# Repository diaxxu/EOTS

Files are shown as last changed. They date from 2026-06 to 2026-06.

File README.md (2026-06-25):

# Project EOTS: Dual-Axis FOC Gimbal
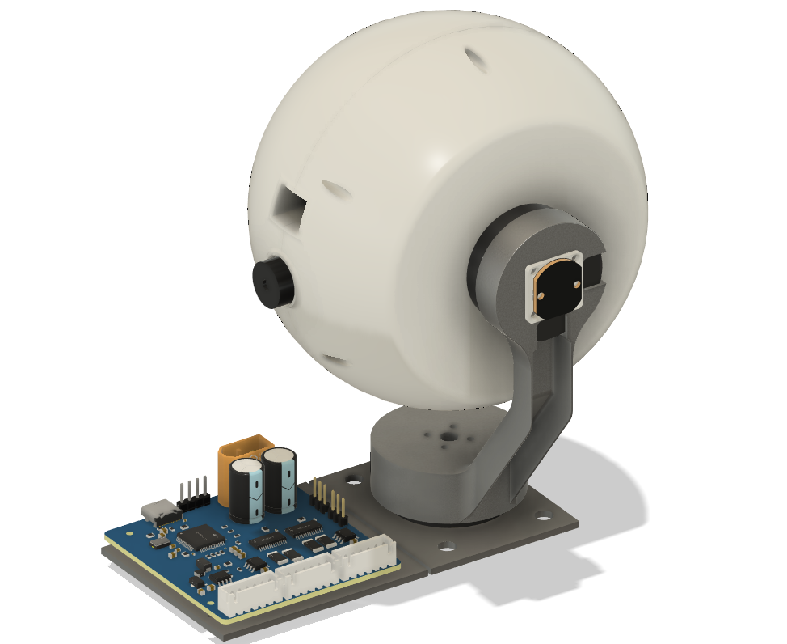
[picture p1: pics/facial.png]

A highly responsive and smooth gimbal capable of tracking targets up to 50m and with the help of two powerful brushless motors its made to be as cheap as possible with almost no drawback it can see thermal vision and normal vision

# Why did i make it

I wanted to build camera system that can track anything say drones, planes and cars. Introducing a high-precision, from-scratch Electro-Optical Targeting System (EOTS). Built with Field Oriented Control (FOC) for continuous, high-torque stabilization, it features a dual-camera sensor payload for synchronized thermal tracking and optical zoom.

- [Project EOTS: Dual-Axis FOC Gimbal](#project-eots-dual-axis-foc-gimbal)
- [Core System Architecture](#core-system-architecture)
  - [Embedded Control & Power Distribution](#embedded-control--power-distribution)
  - [Mechatronics & Actuation](#mechatronics--actuation)
  - [Optical Payload](#optical-payload)
- [(BOM)](#hardware-manifesto-bom)

---

##  Repository Structure

```text
Project-EOTS/
├── README.md                      
├── BOM.csv                        
├── zine.pdf                       
│
├── PCB/                     
│   ├── gerbers.zip                
│   ├── eots_schematic.json     
│   └── BOM.csv
│   └── PickAndPlace.csv
│
├── CAD/                    
│   ├── Assembly      
│   ├── 3d printables
│   ├── 3D metal printing│
│   ├── EOTS.step
│
└── Firmware/                      
    ├── FOC_Gimbal_Driver_STM32/   
    │   ├── main.cpp              
    │   └── platformio.ini         
    │
    ├── RPi_Zero2W_Camera_Server/  
    │   ├── stream_server.py      
    │   └── requirements.txt       
    │
    └── Ground_Control_Station/    
        ├── main.py                
        ├── tracking.py            
        └── hud_display.py
```

# Core System Architecture

The custom 4-layer control board isolates high-frequency digital lines from high-current motor return paths to preserve analog signal integrity. 

## Embedded Control & Power Distribution
* **Microcontroller:** STM32F405RGT6 running custom embedded FOC loops.
* **Gate Drivers:** Dual DRV8313 triple half-bridge drivers managing motor phase currents.
* **Interconnects:** 6-pin JST-XH vertical locking headers (B6B-XH-A) route encoder inputs directly into the MCU timers.
* **Power Delivery:** Main system power is distributed via a high-amperage XT60 connector.
### Schematics 
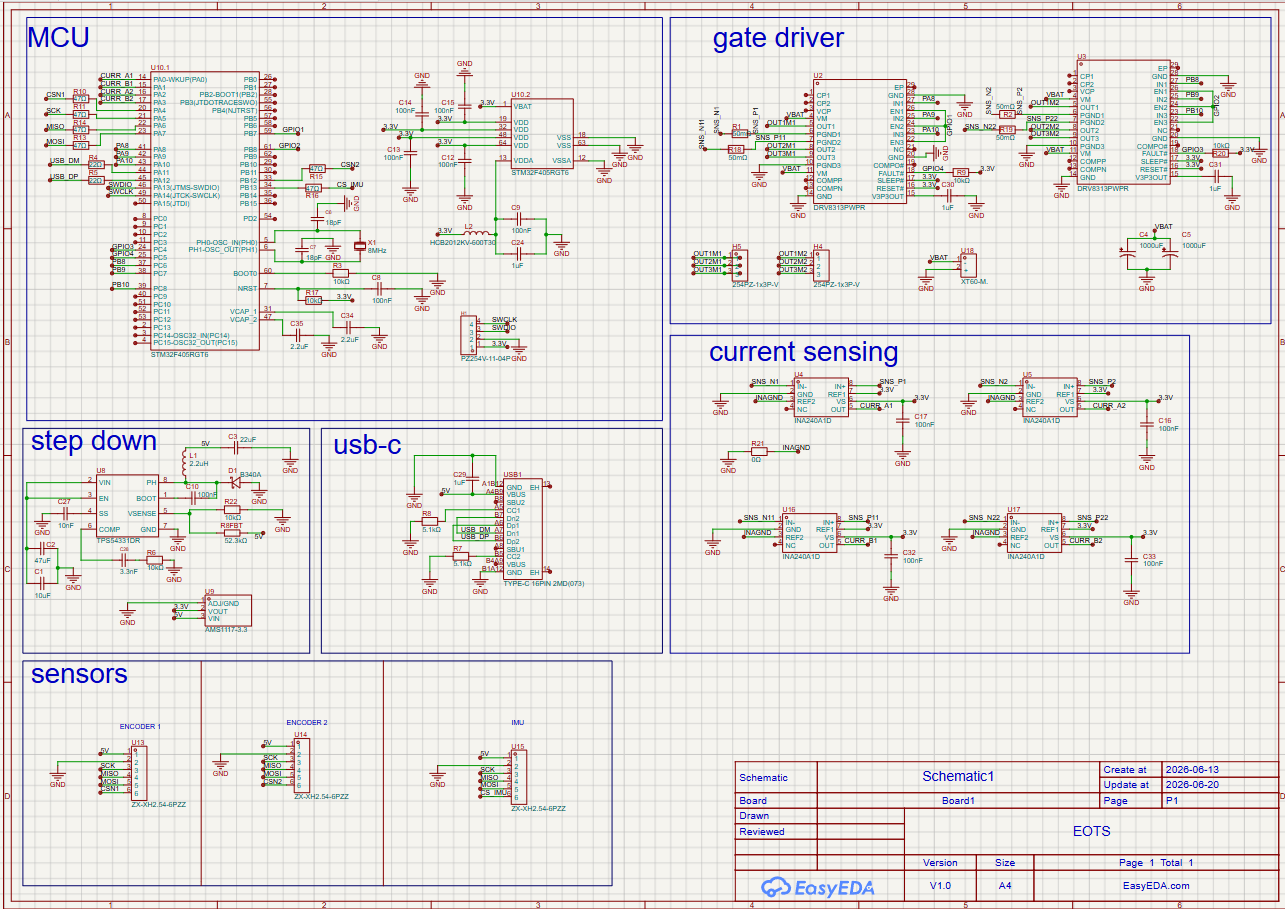
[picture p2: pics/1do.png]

### Layout
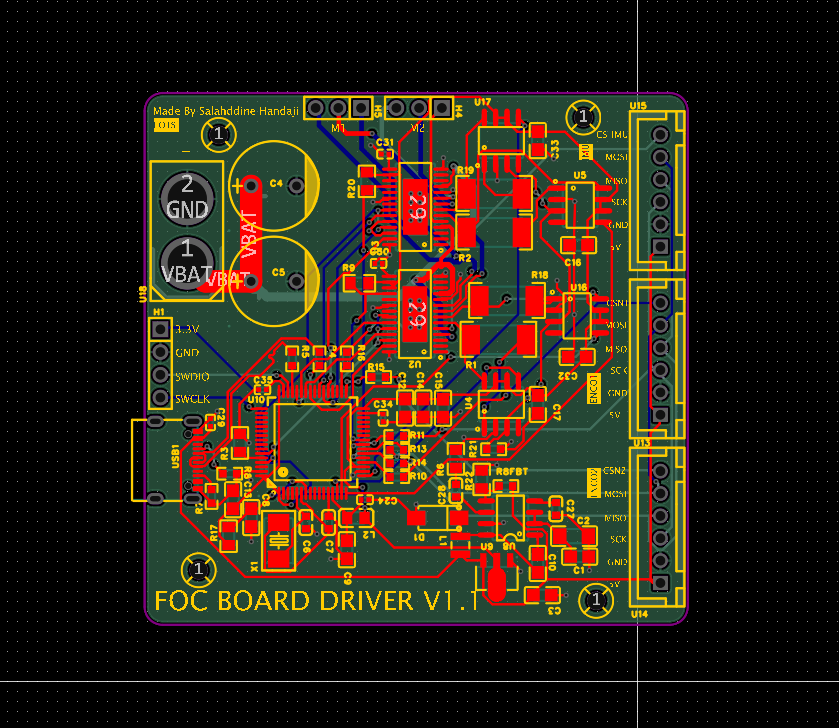
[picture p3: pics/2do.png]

### 3D render
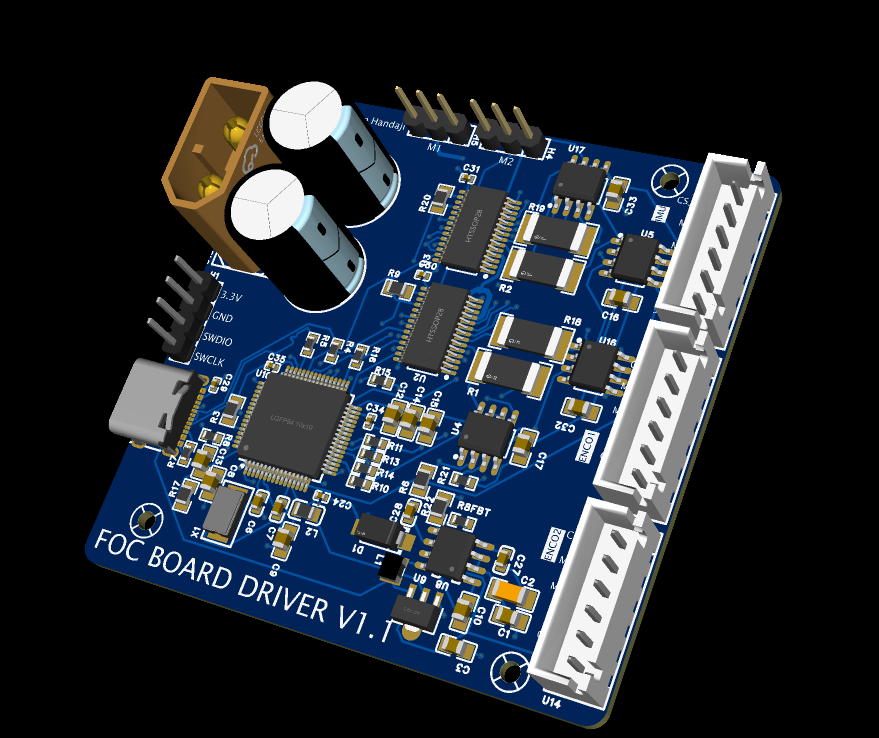
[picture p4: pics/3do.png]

## Mechatronics & Actuation
The mechanical assembly routes power and signals through continuous rotational axes without tangling internal wiring.
* **Actuators:** Dual 2804 100KV brushless motors hard-mounted directly to the structural yoke arms.
* **Sensor Fusion:** An MPU9250 IMU tracks high-speed orientation dynamics in real-time.
* **Feedback Loop:** AS5048A magnetic rotary encoders paired with shaft-mounted diametric neodymium magnets handle absolute angular tracking down to 14-bit resolution.
* **Slip Ring Integration:** A 12-channel MSC-22-12 high-speed capsule slip ring passes continuous USB-C video data through the rotating non-motor pivot arm.
* **Metal chassis:** Metal 3D Printed arm to provide more than enough stability and rigidity.  

## Optical Payload
The sealed sphere housing protects a dual-sensor array running image processing loops back to a central hub.
* **Primary Optical:** IMX219 high-resolution camera module for target detection and optical zoom tracking.
* **Thermal Matrix:** AMG8833 8x8 infrared thermopile array for long-wave thermal signature targeting.
* **Processing Unit:** Raspberry Pi Zero 2 W handles localized video streaming, telemetry generation, and targeting overlays.
  
---

##  How to Use It

Follow these steps to set up, flash, assemble, and operate the EOTS gimbal:

### 1. Hardware Assembly & Mechanical Setup
* **Mount the Actuators:** Secure the two 2804 100KV brushless motors into their respective pan and tilt axis slots on the custom metal 3D-printed yoke chassis.
* **Route the Wiring:** Feed the motor and camera wiring through the center of the 12-wire slip ring to ensure the panning axis can rotate infinitely without binding or straining the cables.
* **Secure the Payload:** Mount the dual-camera housing (containing the IMX219 optical camera and AMG8833 thermal array) onto the tilt axis bracket, ensuring the AS5048A magnetic encoders align perfectly with the motor magnets for precise feedback.

### 2. Flashing the FOC Board Firmware
* **Connect to Power/Data:** Plug a USB-C data cable into the onboard port of the custom FOC driver board.
* **Compile & Flash:** Open the source code located in the `/Firmware` directory using your preferred IDE (e.g., VS Code with PlatformIO or Arduino IDE). Select the correct target MCU board and upload the firmware.
* **Calibrate Encoders:** Run the initial calibration routine embedded in the firmware to map the absolute zero-position of the AS5048A magnetic sensors relative to the brushless motor poles.

### 3. System Interconnect & Operation
* **Power Delivery:** Provide main system power via the dedicated power terminals on the custom PCB (ensure voltage matches your motor/driver design limits).
* **Establish Data Links:** Hook up the Raspberry Pi Zero 2 W to the camera payload feeds and connect its communication lines (UART/SPI) to the FOC driver board to transmit tracking adjustments.
* **Initiate Tracking:** Run your external tracking pipeline (such as an OpenCV script processing the video feed) to send real-time target coordinate errors to the gimbal, allowing the closed-loop FOC system to stabilize and lock onto the target.

### Wire Diagram 
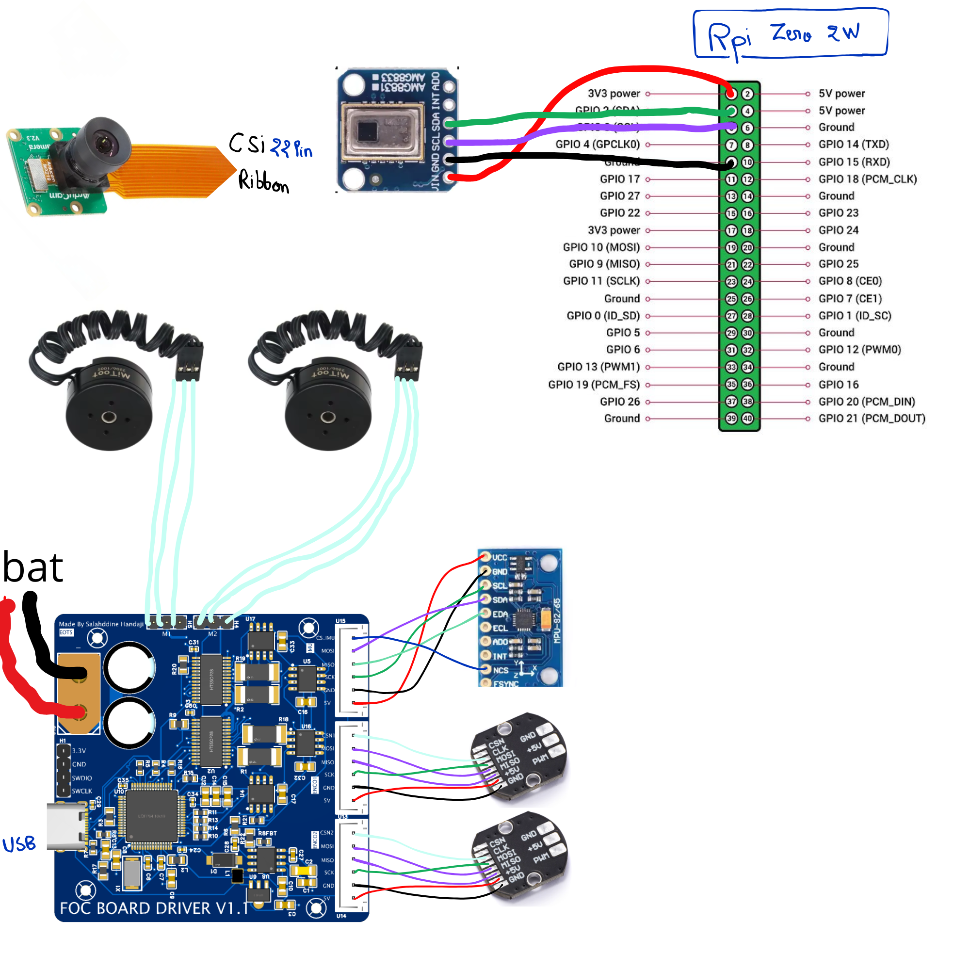
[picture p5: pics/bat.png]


---

# Bill of Materials (BOM)

| Components | Quantity | Price (dh) | Description |
|:---|:---:|:---|:---|
| 2804 100KV Brushless Mo | 2 | 345.42 | Actuators |
| FOC custom pcb | 1 | 1130.99 | Pcb 5 pcba 2 |
| AS5048A | 2 | 194 | Magnetic Encoders magnet included |
| MPU9250 | 1 | OWNED(10) | IMU |
| IMX 219 | 1 | 154.29 | Camera |
| AMG8833 | 1 | 218 | Thermal camera |
| Raspberry Pi Zero 2 W | 1 | 280.00 | Receive camera feeds |
| Slip ring | 1 | 87.83 | 12 Wire slip ring |
| custom chassis | 1 | 296.03 | Metal 3d printed yoke |
| 3d print shipping fee | 1 | 300 | 3d printing legion fee |
| M2/M2.5/M3 screws kit | 1 | 112.96 | m2 m2.5 m3 screws 4/5/6/8mm pitch |
| JST-XH | 5 | 33.6 | Connectors |

### Budget Summary
* **Total Cost:** `3,163.12dh` 
* **Total in USD :** `~$341.8 USD` FROM 410$ to this thanks to optimization in the bom 

# PICS 
## zine 
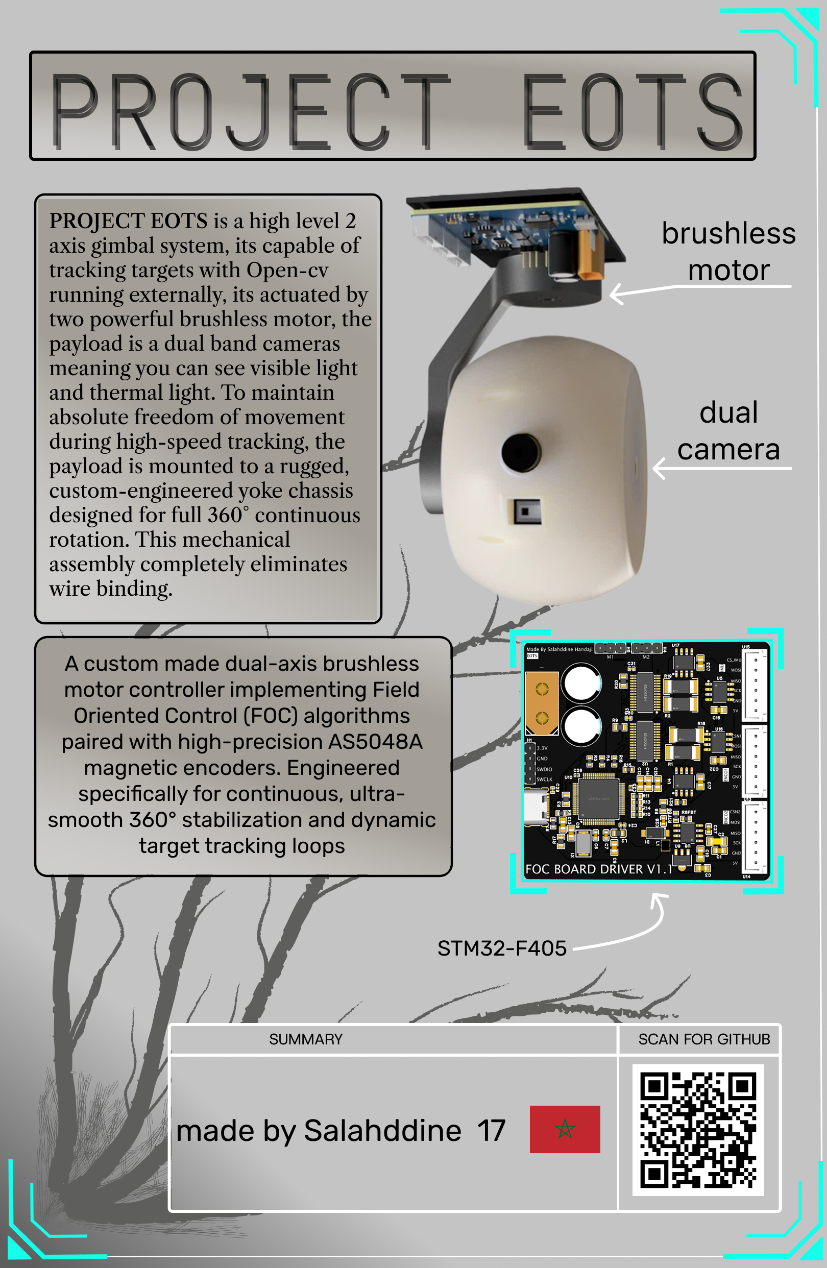
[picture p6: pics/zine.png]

## renders 
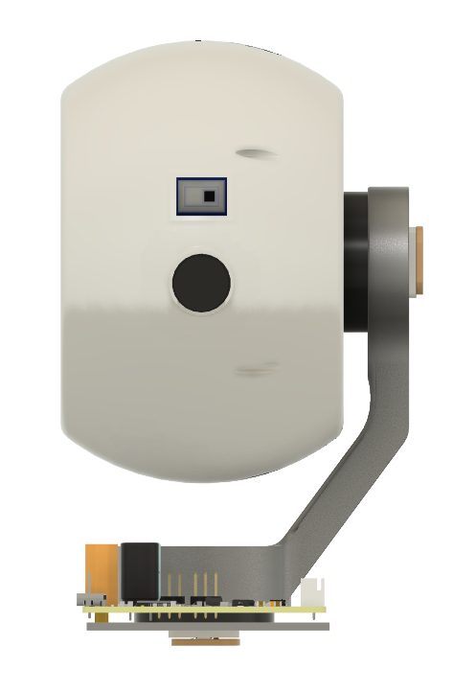
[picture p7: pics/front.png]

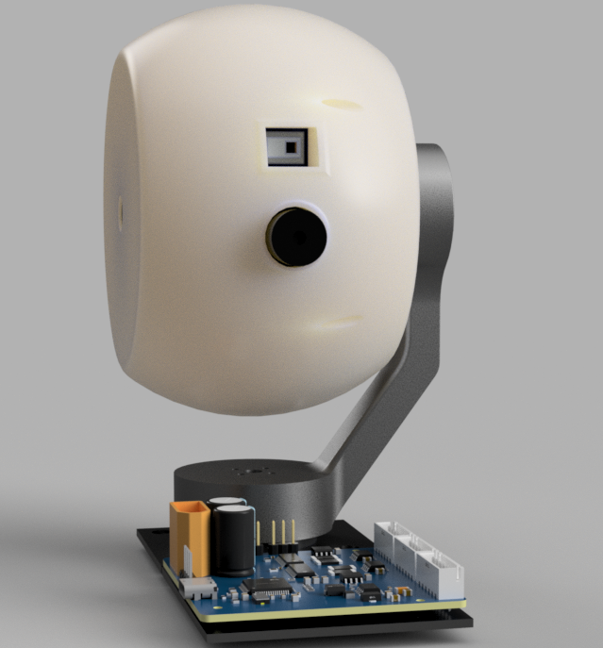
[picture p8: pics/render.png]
EOTS 3D CAD Render

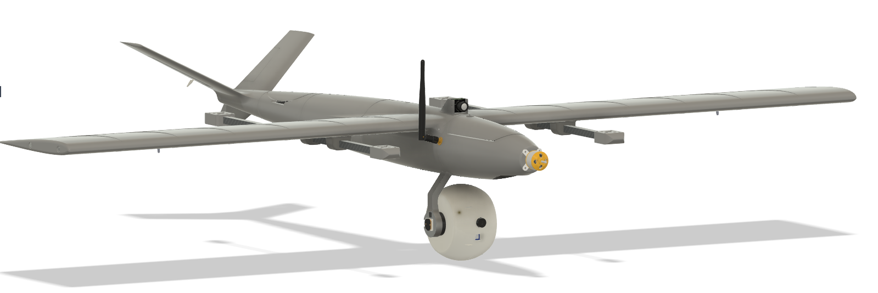
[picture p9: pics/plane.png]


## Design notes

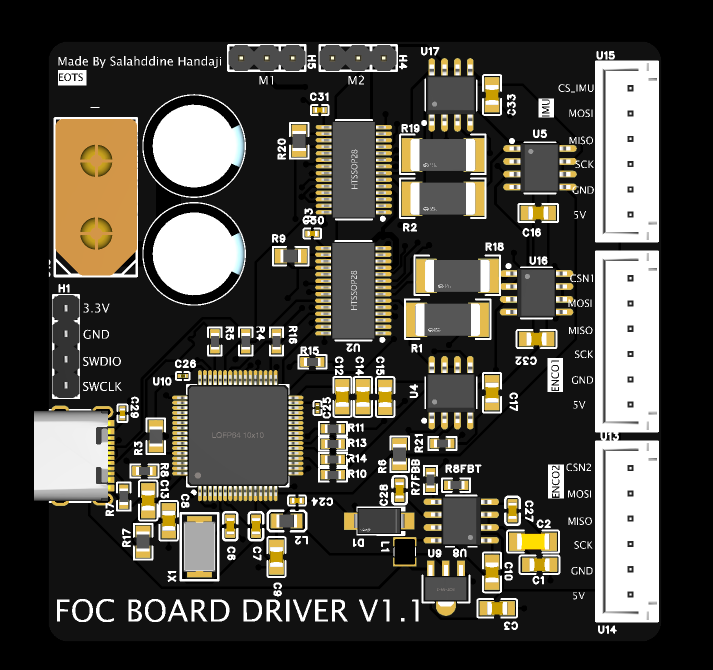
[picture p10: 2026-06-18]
pics/real.png

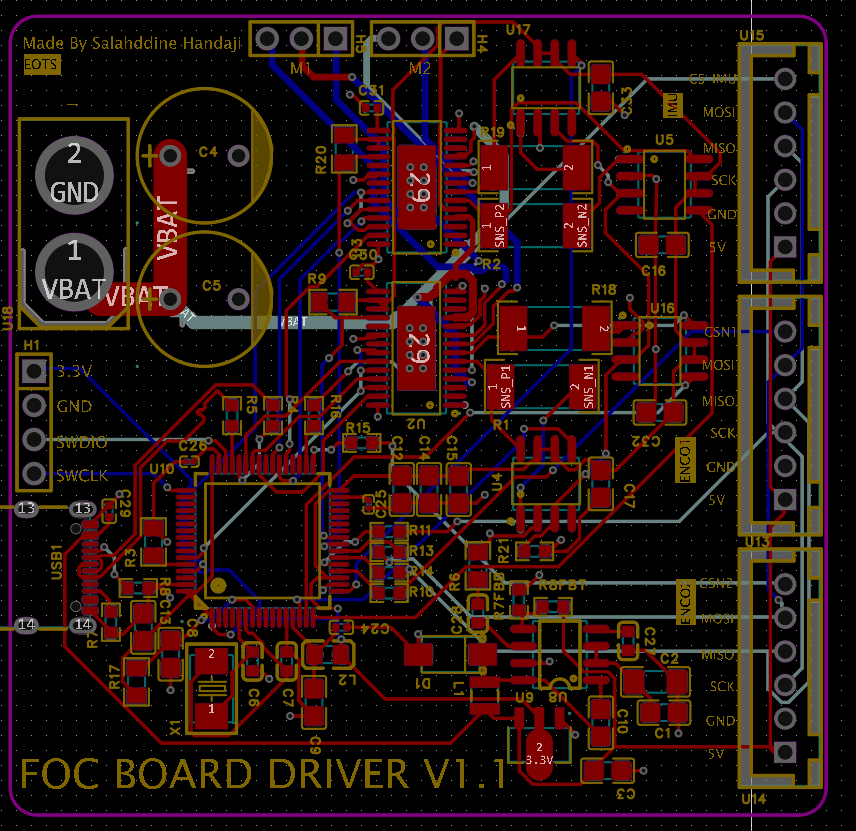
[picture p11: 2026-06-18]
pics/pcb.png

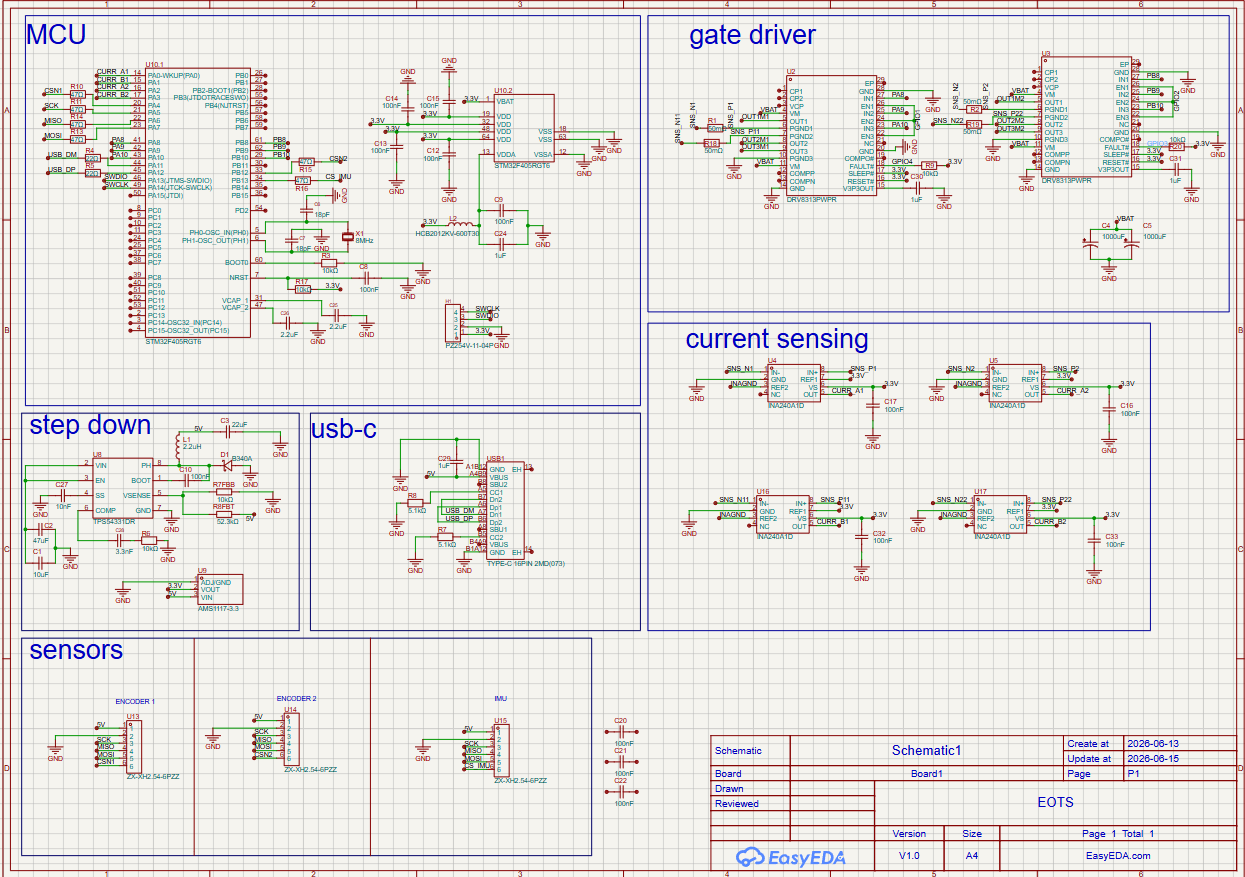
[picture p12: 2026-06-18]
pics/schem.png

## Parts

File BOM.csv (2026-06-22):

Components | Quantity | Price ( dh) | Description | LINK
2804 100KV Brushless Motors | 2 | 345.42 | Actuators | https://www.aliexpress.com/item/1005012203438661.html?spm=a2g0o.productlist.0.0.11ee26cdiME4i7&mp=1
FOC custom pcb | 1 | 1130.99 | Pcb 5 pcba 2 | jlcpcb.com
AS5048A | 2 | 194 | Magnetic Encoders magnet included | https://www.aliexpress.com/item/1005009516781005.html?spm=a2g0o.cart.0.0.5d5d378dXW3cyR&mp=1
MPU9250 | 1 | OWNED(10) | IMU
IMX 219 | 1 | 154.29 | Camera | https://www.aliexpress.com/item/1005003774526287.html?mp=1
AMG8833 | 1 | 218 | Thermal camera | https://www.aliexpress.com/item/1005001852981269.html?spm=a2g0o.cart.0.0.5d5d378dXW3cyR&mp=1
Raspberry Pi Zero 2 W | 1 | 280,00 | Receive camera feeds | https://aytoo.ma/produit/raspberry-pi-zero-2-w/
Slip ring | 1 | 87.83 | 12 Wire slip ring | https://www.aliexpress.com/item/4000982871775.html?spm=a2g0o.cart.0.0.5d5d378dXW3cyR&mp=1
custom chassis | 1 | 296.03 | Metal 3d printed yoke | jlc3dp
3d print shipping fee | 1 | 300 | 3d printing legion fee | printing LEGION
M2/M2.5/M3 screws kit | 1 | 112.96 | m2 m2.5 m3 screws 4/5/6/8mm pitch | https://www.aliexpress.com/item/1005010777076859.html?spm=a2g0o.cart.0.0.5d5d378dXW3cyR&mp=1
JST-XH | 5 | 33.6 | Connectors | https://www.aliexpress.com/item/1005007389108799.html?spm=a2g0o.cart.0.0.5d5d378dXW3cyR&mp=1
 |  | TOTAL : 3,163.12dh (341.8$)

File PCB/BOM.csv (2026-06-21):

 |  |  |  |  |  |  |  |  |  |  |  | Order Information
Top Designator | Bottom Designator | Comment | Footprint | JLCPCB Part # | Matches | Part # | Manufacturer | Footprint | Description | Category | Warning | JLCPCB Part # | Product link | Lib Type | Qty | Source | Total Price ($)
C1 |  | 10uF | C0805 |  | Select by Customer | CL21A106KAYNNNE | Samsung Electro-Mechanics | 0805 | 10uF 25V X5R ±10% 0805 Multilayer Ceramic Capacitors MLCC - SMD/SMT ROHS | Multilayer Ceramic Capacitors MLCC - SMD/SMT |  | C15850 | https://jlcpcb.com/partdetail/16532-CL21A106KAYNNNE/C15850 | Basic | 20 | 20 JLCPCB | 1.532
C2 |  | 47uF | C1206 |  | Select by Customer | CL31A476MPHNNNE | Samsung Electro-Mechanics | 1206 | 10V 47uF X5R ±20% 1206 Multilayer Ceramic Capacitors MLCC - SMD/SMT ROHS | Multilayer Ceramic Capacitors MLCC - SMD/SMT |  | C96123 | https://jlcpcb.com/partdetail/97327-CL31A476MPHNNNE/C96123 | Basic | 6 | 6 JLCPCB | 1.1352
C3 |  | 22uF | C0805 |  | Select by Customer | CL21A226MAQNNNE | Samsung Electro-Mechanics | 0805 | 22uF 25V X5R ±20% 0805 Multilayer Ceramic Capacitors MLCC - SMD/SMT ROHS | Multilayer Ceramic Capacitors MLCC - SMD/SMT |  | C45783 | https://jlcpcb.com/partdetail/46786-CL21A226MAQNNNE/C45783 | Basic | 10 | 10 JLCPCB | 1.174
C4,C5 |  | 1000uF | CAP-TH_BD10.0-P5.00-D1.0-FD |  | Select by System | ERR1VM102G20OT | AISHI(Aihua Group) | ??,D10xL20mm | 1000uF 10mm 2000hrs@105? 20mm 35V 5mm ±20% ??,D10xL20mm Aluminum Electrolytic Capacitors - Leaded ROHS | Aluminum Electrolytic Capacitors - Leaded |  | C398835 | https://jlcpcb.com/partdetail/AISHI_Aihua_Group-ERR1VM102G20OT/C398835 | Extended | 0 | 0 JLCPCB | 0
C6,C7 |  | 18pF | C0603 |  | Select by Customer | CL10C180JB8NNNC | Samsung Electro-Mechanics | 0603 | 18pF 50V C0G ±5% 0603 Multilayer Ceramic Capacitors MLCC - SMD/SMT ROHS | Multilayer Ceramic Capacitors MLCC - SMD/SMT |  | C1647 | https://jlcpcb.com/partdetail/1999-CL10C180JB8NNNC/C1647 | Basic | 20 | 20 JLCPCB | 0.194
C8,C9,C10,C12,C13,C14,C15,C16,C17,C32,C33 |  | 100nF | C0805 |  | Select by Customer | CL21B104KCFNNNE | Samsung Electro-Mechanics | 0805 | 100V 100nF X7R ±10% 0805 Multilayer Ceramic Capacitors MLCC - SMD/SMT ROHS | Multilayer Ceramic Capacitors MLCC - SMD/SMT |  | C28233 | https://jlcpcb.com/partdetail/28983-CL21B104KCFNNNE/C28233 | Basic | 32 | 32 JLCPCB | 0.9664
C24,C29,C30,C31 |  | 1uF | C0402 |  | Select by Customer | CL05A105KA5NQNC | Samsung Electro-Mechanics | 0402 | 1uF 25V X5R ±10% 0402 Multilayer Ceramic Capacitors MLCC - SMD/SMT ROHS | Multilayer Ceramic Capacitors MLCC - SMD/SMT |  | C52923 | https://jlcpcb.com/partdetail/53938-CL05A105KA5NQNC/C52923 | Basic | 20 | 20 JLCPCB | 0.312
C25,C26 |  | 2.2uF | C0201 |  | Select by Customer | CL05A225MQ5NSNC | Samsung Electro-Mechanics | 0402 | 2.2uF 6.3V X5R ±20% 0402 Multilayer Ceramic Capacitors MLCC - SMD/SMT ROHS | Multilayer Ceramic Capacitors MLCC - SMD/SMT |  | C12530 | https://jlcpcb.com/partdetail/13164-CL05A225MQ5NSNC/C12530 | Basic | 20 | 20 JLCPCB | 0.154
C27 |  | 10nF | C0603 |  | Select by Customer | 0603B103K500NT | FH (Guangdong Fenghua Advanced Tech) | 0603 | 10nF 50V X7R ±10% 0603 Multilayer Ceramic Capacitors MLCC - SMD/SMT ROHS | Multilayer Ceramic Capacitors MLCC - SMD/SMT |  | C57112 | https://jlcpcb.com/partdetail/58143-0603B103K500NT/C57112 | Basic | 20 | 20 JLCPCB | 0.564
C28 |  | 3.3nF | C0603 |  | Select by Customer | CL10B332KB8NNNC | Samsung Electro-Mechanics | 0603 | 3.3nF 50V X7R ±10% 0603 Multilayer Ceramic Capacitors MLCC - SMD/SMT ROHS | Multilayer Ceramic Capacitors MLCC - SMD/SMT |  | C1613 | https://jlcpcb.com/partdetail/1965-CL10B332KB8NNNC/C1613 | Basic | 20 | 20 JLCPCB | 0.172
D1 |  | B340A | SMA_L4.3-W2.6-LS5.0-RD |  | Select by System | B340A | hongjiacheng | SMA | -55?~+150? 1 Independent 100A 3A 40V 50uA@40V 550mV@3A SMA Schottky Diodes ROHS | Schottky Diodes |  | C48642440 | https://jlcpcb.com/partdetail/hongjiacheng-B340A/C48642440 | Extended | 6 | 6 JLCPCB | 0.3456
H1 |  | PZ254V-11-04P | HDR-TH_4P-P2.54-V-M |  | Select by System | PZ254V-11-04P | XFCN | ??,P=2.54mm | -40?~+105? 1 1x4P 2.54mm 2.5mm 250V 3A 3mm 4P 6mm Black Pin Header Through Hole ??,P=2.54mm Pin Headers ROHS | Pin Headers |  | C2691448 | https://jlcpcb.com/partdetail/XFCN-PZ254V_1104P/C2691448 | Extended | 0 | 0 JLCPCB | 0
H4,H5 |  | 254PZ-1x3P-V | HDR-TH_3P-P2.54-V-M |  | Select by System | 254PZ-1x3P-V | LXWCONN | ??,P=2.54mm | 1 1x3P 2.54mm Pin Header Through Hole ??,P=2.54mm Pin Headers ROHS |  |  | C53055673 | https://jlcpcb.com/partdetail/LXWCONN-254PZ_1x3PV/C53055673 | Extended | 0 | 0 JLCPCB | 0
L1 |  | 2.2uH | IND-SMD_L2.5-W2.0_MHCHL2520 |  | Select by System | FTC252012S2R2MBCA | cjiang (Changjiang Microelectronics Tech) | 1008 | 2.2uH 3.8A 3A 55m? ±20% 1008 Power Inductors ROHS | Power Inductors |  | C5832372 | https://jlcpcb.com/partdetail/6763492-FTC252012S2R2MBCA/C5832372 | Extended | 6 | 6 JLCPCB | 0.204
L2 |  | HCB2012KV-600T30 | L0805 |  | Select by Customer | GZ2012D101TF | Sunlord | 0805 | 1 100?@100MHz 150m? 800mA ±25% 0805 Ferrite Beads ROHS | Ferrite Beads |  | C1015 | https://jlcpcb.com/partdetail/Sunlord-GZ2012D101TF/C1015 | Basic | 20 | 20 JLCPCB | 0.616
R1,R2,R18,R19 |  | 50m? | RES-SMD_L6.4-W3.2-R2512 |  | Select by System | RE2512F3R050 | jieerrui | 2512 | 3W 50m? Alloy Resistor?Current Sense Resistor SMD ±1% ±50ppm/? 2512 Current Sense Resistors / Shunt Resistors ROHS | Current Sense Resistors / Shunt Resistors |  | C46961759 | https://jlcpcb.com/partdetail/jieerrui-RE2512F3R050/C46961759 | Extended | 10 | 10 JLCPCB | 0.991
R3,R6,R9,R17,R20 |  | 10k? | R0805 |  | Select by Customer | 0805W8F1002T5E | UNI-ROYAL(Uniroyal Elec) | 0805 | -55?~+155? 10k? 125mW 150V Thick Film Resistor ±1% ±100ppm/? 0805 Chip Resistor - Surface Mount ROHS | Chip Resistor - Surface Mount | 1.Multiple lines in the BOM have been matched to the same part. Please check if the matching is correct. ; | C17414 | https://jlcpcb.com/partdetail/18102-0805W8F1002T5E/C17414 | Basic | 22 | 22 JLCPCB | 0.0748
R7FBB |  | 10k? | R0603 |  | Select by Customer | 0805W8F1002T5E | UNI-ROYAL(Uniroyal Elec) | 0805 | -55?~+155? 10k? 125mW 150V Thick Film Resistor ±1% ±100ppm/? 0805 Chip Resistor - Surface Mount ROHS | Chip Resistor - Surface Mount | 1.Multiple lines in the BOM have been matched to the same part. Please check if the matching is correct. ; | C17414 | https://jlcpcb.com/partdetail/18102-0805W8F1002T5E/C17414 | Basic | 22 | 22 JLCPCB | 0.0748
R4,R5 |  | 22? | R0603 |  | Select by Customer | 0603WAF220JT5E | UNI-ROYAL(Uniroyal Elec) | 0603 | -55?~+155? 100mW 22? 75V Thick Film Resistor ±1% ±100ppm/? 0603 Chip Resistor - Surface Mount ROHS | Chip Resistor - Surface Mount |  | C23345 | https://jlcpcb.com/partdetail/24078-0603WAF220JT5E/C23345 | Basic | 20 | 20 JLCPCB | 0.034
R7,R8 |  | 5.1k? | R0603 |  | Select by Customer | 0603WAF5101T5E | UNI-ROYAL(Uniroyal Elec) | 0603 | -55?~+155? 100mW 5.1k? 75V Thick Film Resistor ±1% ±100ppm/? 0603 Chip Resistor - Surface Mount ROHS | Chip Resistor - Surface Mount |  | C23186 | https://jlcpcb.com/partdetail/23913-0603WAF5101T5E/C23186 | Basic | 20 | 20 JLCPCB | 0.038
R10,R11,R13,R14,R15,R16 |  | 47? | R0603 |  | Select by Customer | 0603WAF470JT5E | UNI-ROYAL(Uniroyal Elec) | 0603 | -55?~+155? 100mW 47? 75V Thick Film Resistor ±1% ±100ppm/? 0603 Chip Resistor - Surface Mount ROHS | Chip Resistor - Surface Mount |  | C23182 | https://jlcpcb.com/partdetail/23909-0603WAF470JT5E/C23182 | Basic | 22 | 22 JLCPCB | 0.0506
R21 |  | 0? | R0603 |  | Select by Customer | 0603WAF0000T5E | UNI-ROYAL(Uniroyal Elec) | 0603 | -55?~+155? 0? 100mW 75V Thick Film Resistor ±1% 0603 Chip Resistor - Surface Mount ROHS | Chip Resistor - Surface Mount |  | C21189 | https://jlcpcb.com/partdetail/21903-0603WAF0000T5E/C21189 | Basic | 20 | 20 JLCPCB | 0.036
R8FBT |  | 52.3k? | R0603 |  | Select by System | 0603WAF5232T5E | UNI-ROYAL(Uniroyal Elec) | 0603 | -55?~+155? 100mW 52.3k? 75V Thick Film Resistor ±1% ±100ppm/? 0603 Chip Resistor - Surface Mount ROHS | Chip Resistor - Surface Mount |  | C23198 | https://jlcpcb.com/partdetail/23925-0603WAF5232T5E/C23198 | Extended | 20 | 20 JLCPCB | 0.026
U2,U3 |  | DRV8313PWPR | HTSSOP-28_L9.8-W4.5-P0.65-LS6.6-BL-EP |  | Select by Customer | DRV8313PWPR | Texas Instruments | HTSSOP-28 | -40?~+125? 2.5A 3 800uA Three Phase Yes HTSSOP-28 Brushless DC (BLDC) Motor Driver ROHS | Brushless DC (BLDC) Motor Driver |  | C92482 | https://jlcpcb.com/partdetail/TexasInstruments-DRV8313PWPR/C92482 | Extended | 4 | 4 JLCPCB | 8.0116
U4,U5,U16,U17 |  | INA240A1D | SOIC-8_L4.9-W3.9-P1.27-LS6.0-BL |  | Select by Customer | INA240A1DR | Texas Instruments | SOIC-8 | -40?~+125? -4V~80V 1 1.8mA 132dB 2.7V~5.5V 20V/V 250nV/? 2V/us 400kHz 40nV/?Hz@1kHz 5uV 90uA ±80V SOIC-8 Current Sense Amplifiers ROHS | Current Sense Amplifiers |  | C2060769 | https://jlcpcb.com/partdetail/TexasInstruments-INA240A1DR/C2060769 | Extended | 8 | 8 JLCPCB | 8.276
U8 |  | TPS54331DR | SOIC-8_L5.0-W4.0-P1.27-LS6.0-BL |  | Select by System | TPS54331DR | Texas Instruments | SOIC-8 | -40?~+150?@(TJ) 1 110uA 3.5V~28V 3A 570kHz 800mV~25V Adjustable Buck Buck Built-in No SOIC-8 DC-DC Converters ROHS | DC-DC Converters |  | C9865 | https://jlcpcb.com/partdetail/TexasInstruments-TPS54331DR/C9865 | Extended | 2 | 2 JLCPCB | 0.7712
U9 |  | AMS1117-3.3 | SOT-89-3_L4.5-W2.5-P1.50-LS4.2-BR |  | Select by Customer | AMS1117-3.3 | Advanced Monolithic Systems | SOT-223 | -40?~+125? 0.003%Vout 1 1.1V@(800mA) 15V 1A 3.3V 5mA 72dB@(120Hz) Fixed Over Current Protection?Short Circuit Protection?Thermal shutdown Positive SOT-223 Voltage Regulators - Linear, Low Drop Out (LDO) Regulators ROHS | Voltage Regulators - Linear, Low Drop Out (LDO) Regulators |  | C6186 | https://jlcpcb.com/partdetail/Advanced_MonolithicSystems-AMS1117_33/C6186 | Basic | 2 | 2 JLCPCB | 0.394
U10 |  | STM32F405RGT6 | LQFP-64_L10.0-W10.0-P0.50-LS12.0-BL |  | Select by Customer | STM32F405RGT6 | STMicroelectronics | LQFP-64(10x10) | -40?~+85? 1.8V~3.6V 12bit 12bit 168MHz 192KB 1MB 32 Bit 51 ARM Cortex-M4 Built-in FLASH LQFP-64(10x10) Microcontrollers (MCU/MPU/SOC) ROHS | Microcontrollers (MCU/MPU/SOC) |  | C15742 | https://jlcpcb.com/partdetail/STMicroelectronics-STM32F405RGT6/C15742 | Extended | 2 | 2 JLCPCB | 8.9236
U13,U14,U15 |  | ZX-XH2.54-6PZZ | CONN-TH_6P-P2.50_ZX-XH2.54-6PZZ |  | Select by Customer | ZX-XH2.54-6PZZ | Megastar | ??,P=2.5mm | -25?~+85? 1 17.5mm 1x6P 2.5mm 250V 2A 5.9mm 6 6P 7mm Brass PA66 Through Hole Tin UL94V-0 White XH ??,P=2.5mm Wire To Board Connector ROHS | Wire To Board Connector |  | C7429636 | https://jlcpcb.com/partdetail/Megastar-ZX_XH2_546PZZ/C7429636 | Extended | 0 | 0 JLCPCB | 0
U18 |  | XT60-M. | CONN-TH_XT60 |  | Select by System | XT60-M. | Changzhou Amass Elec | - | -?Banana Connector 3.5mm Male Yellow - Power connector / plug connector | Plug |  | C98733 | https://jlcpcb.com/partdetail/Changzhou_AmassElec-XT60_M/C98733 | Extended | 0 | 0 JLCPCB | 0
USB1 |  | TYPE-C16PIN2MD(073) | USB-C-SMD_TYPE-C-16PIN-2MD-073 |  | Select by System | TYPE-C 16PIN 2MD(073) | SHOU HAN | SMD | -25?~+85? 1 16P 3A 5,000 times 5V Black Female Surface Mount, Right Angle Type-C SMD USB Connectors ROHS | USB Connectors |  | C2765186 | https://jlcpcb.com/partdetail/SHOUHAN-TYPE_C_16PIN_2MD_073/C2765186 | Extended | 3 | 3 JLCPCB | 0.2205
X1 |  | 8MHz | CRYSTAL-SMD_L5.0-W3.2 |  | Select by Customer | X50328MSB2GI | YXC Crystal Oscillators | SMD5032-2P | -40?~+85? 20pF 8MHz Crystal Oscillator ±10ppm ±20ppm SMD5032-2P Crystals ROHS | Crystals |  | C115962 | https://jlcpcb.com/partdetail/YXC_CrystalOscillators-X50328MSB2GI/C115962 | Basic | 5 | 5 JLCPCB | 1.337
 |  |  |  |  |  |  |  |  |  |  |  |  |  |  |  |  | Total Price?36.6283$

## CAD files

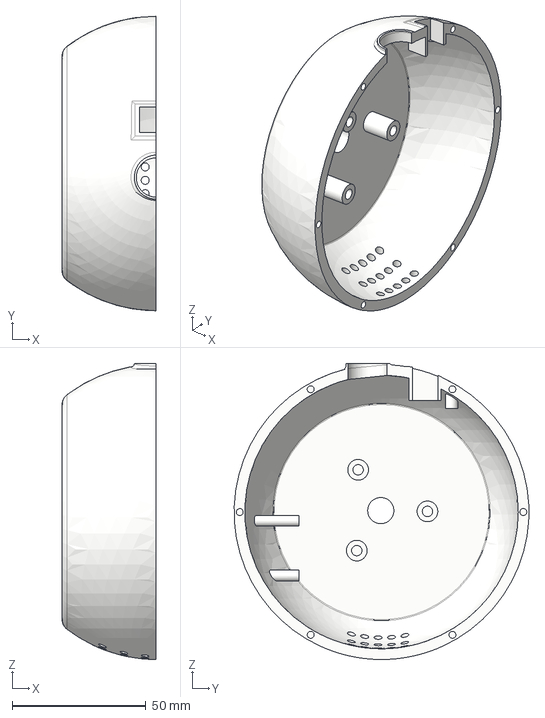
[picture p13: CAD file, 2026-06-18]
CAD/3D printables/3d print1.step
35.1 x 110.1 x 110.7 mm

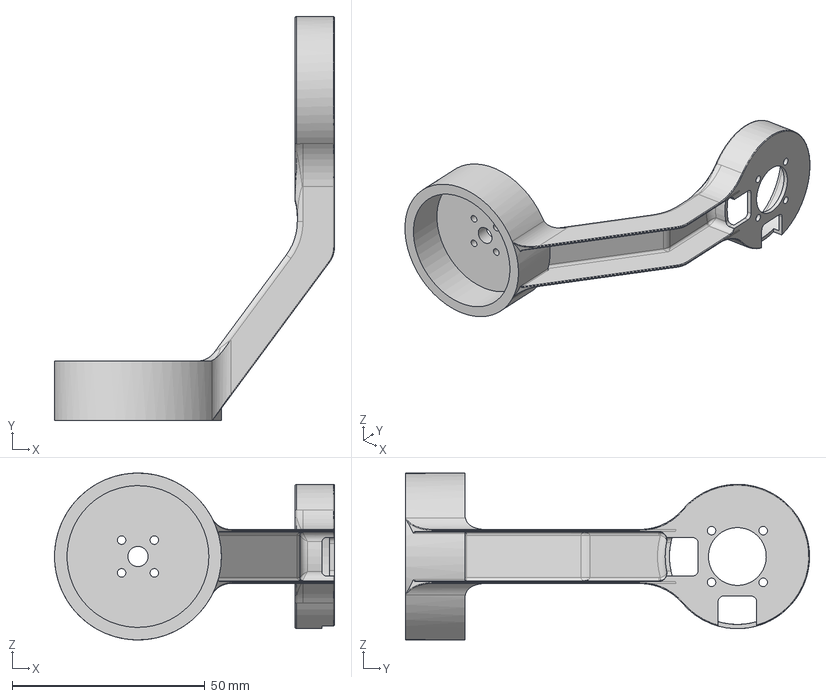
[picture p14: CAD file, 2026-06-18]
CAD/METAL 3D PRINTABLES/chassis.step
72.7 x 104.9 x 43.3 mm

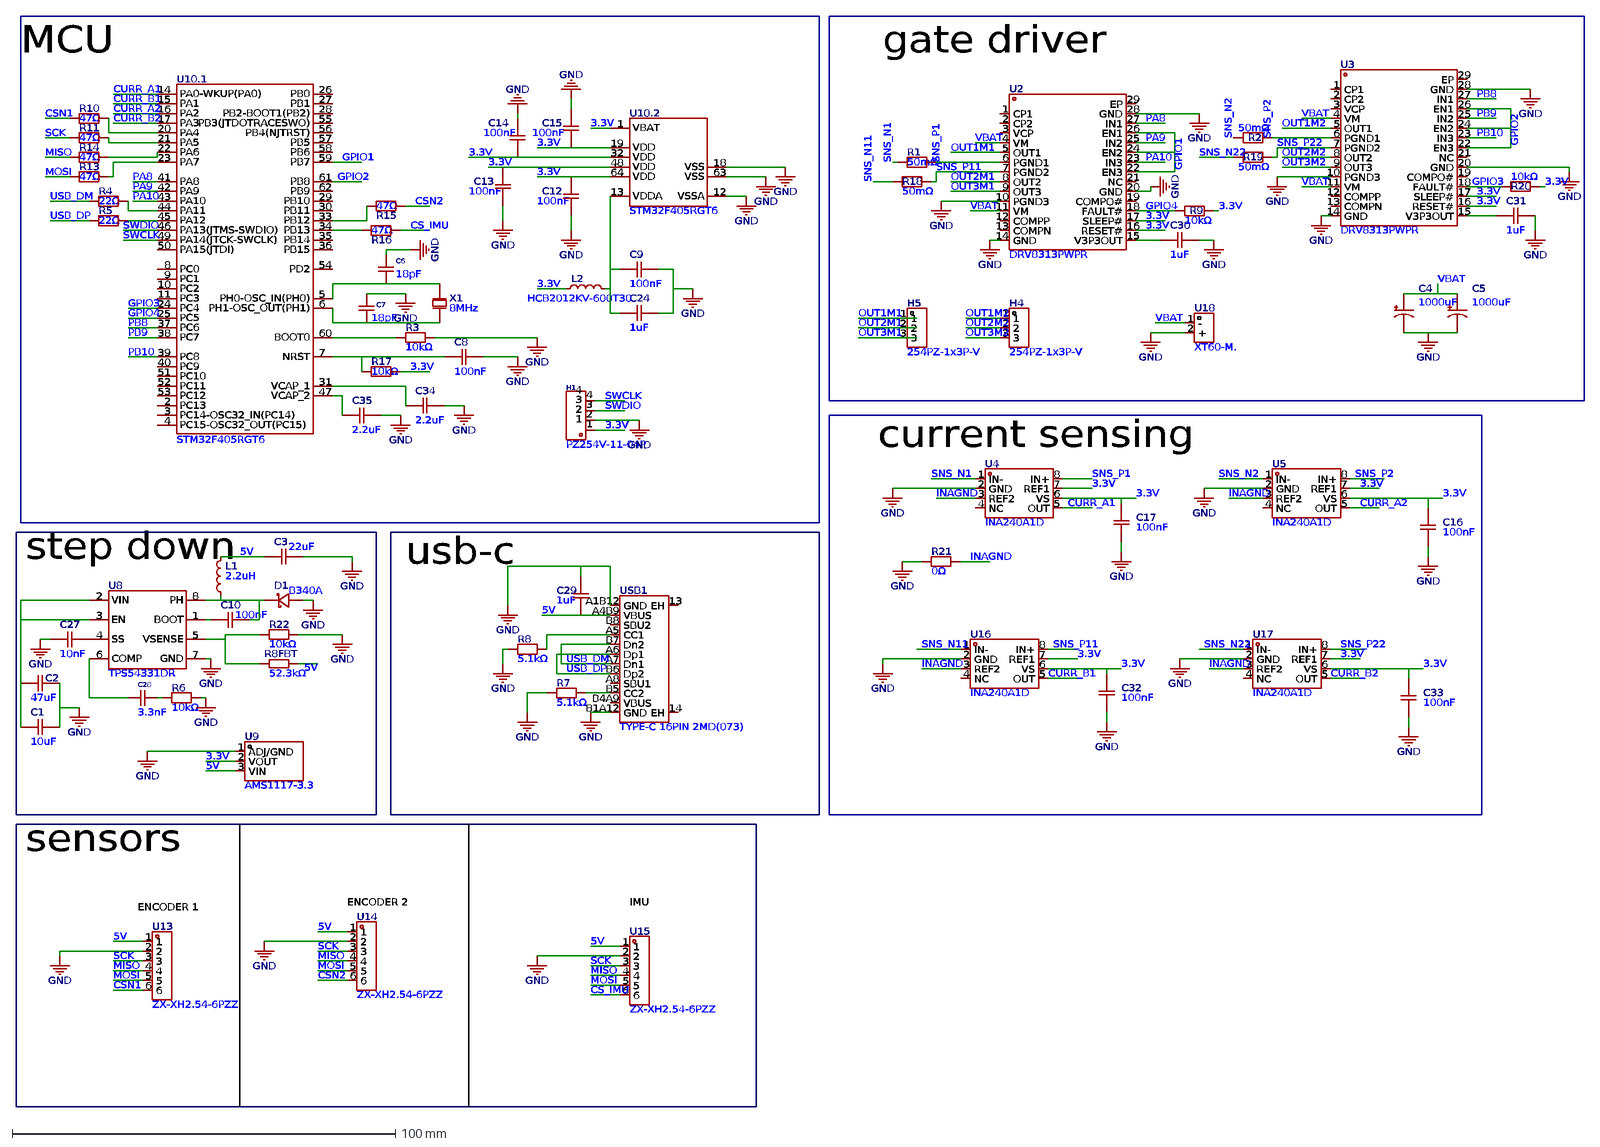
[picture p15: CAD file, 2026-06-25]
PCB/1_P1.dxf
DRV8313PWPR
U2
CP1
1
CP2
2
VCP
3
VM
4
OUT1
5
PGND1
6
PGND2
7
OUT2
8
OUT3
9
PGND3
10
11
COMPP
12
COMPN
13
GND
14
V3P3OUT
15
RESET#
16
SLEEP#
17
FAULT#
18
COMPO#
19
20
NC
21
EN3
22
IN3
23
EN2
24
IN2
25
EN1
26
IN1
27
28
EP
29
U3
INA240A1D
U4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

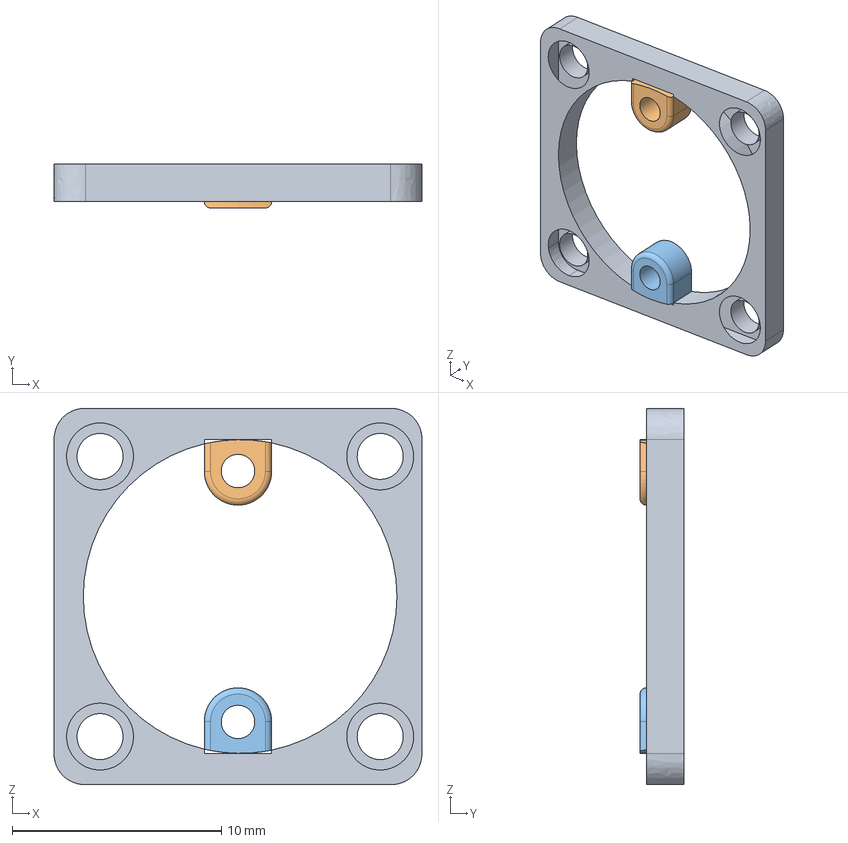
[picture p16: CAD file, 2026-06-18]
CAD/3D printables/encoder mount.step
17.6 x 2.10 x 18.0 mm

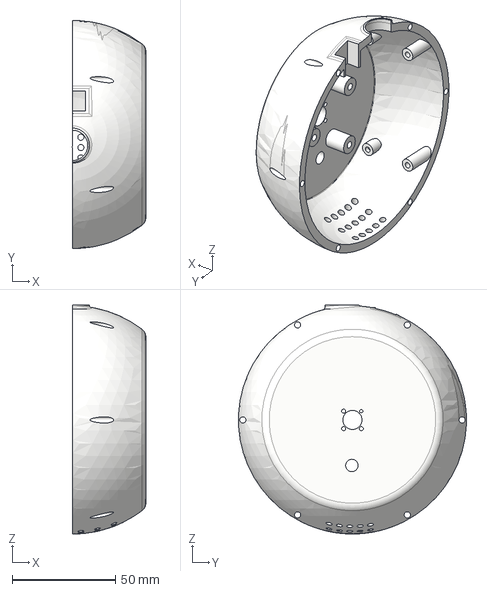
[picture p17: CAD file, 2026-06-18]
CAD/3D printables/3d print.step
35.6 x 110.1 x 110.7 mm

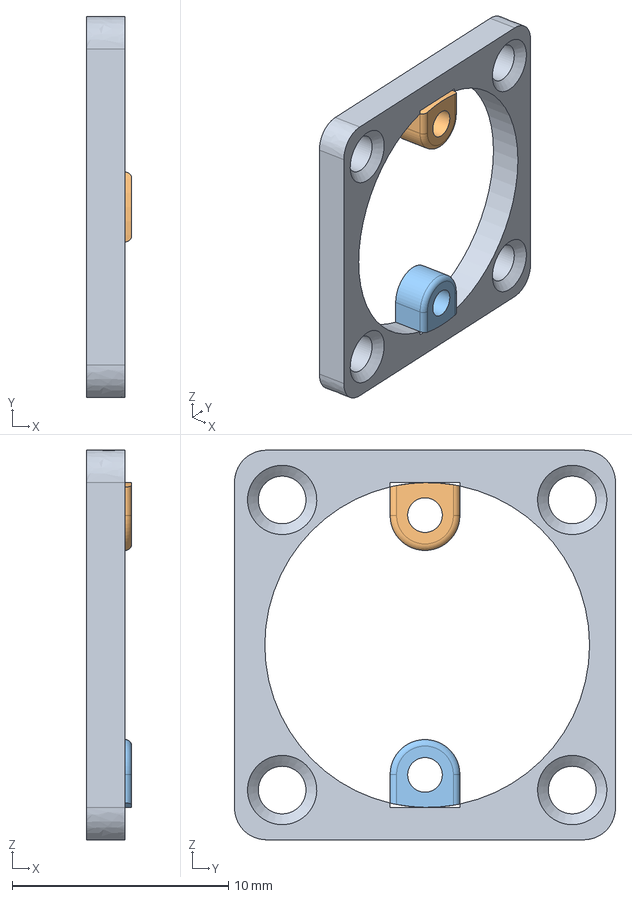
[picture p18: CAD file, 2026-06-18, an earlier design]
CAD/3D printables/encoder mount (1).step
2.10 x 17.6 x 18.0 mm

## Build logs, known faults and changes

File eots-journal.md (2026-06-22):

# EOTS  — Journal Export

- Exported at: 2026-06-22T15:51:53Z
- Project ID: 4547
- Entries: 9

## Entry 1
- ID: 14120
- Author: diaxx
- Created At: 2026-06-14T23:48:10Z

### Content

## starting a new project 

this project is a eots ( electro optical targeting system ) it works like a gimbal can rotate and pan since its a 2 axis because 3 axis cost is not justified thats why i went with two axis in this journal i made a lot of advancement i created the chassis the gimbal interior added component such as the motor , rasberry pi zero 0 and camera which consist of 2 spectrum camera we call this a dual band EO so i have a day / night camera and a thermal camera ( its a 8x8 camera its good enough for me i can do fusion between those two ) the reason on why i decided to make this project is that i love gimbal and electro optics the feeling when you can track something with just a click of a button a passing car for exemple ( shit this doesn't sound good ) 
Capture d'écran 2026-06-14 041628.png
Capture d'écran 2026-06-14 023041.png
 next i am going to build the foc ( field oriented control ) board so i can precisely control those bldc motors and i will build the gcs ( ground control station ) out of python !!! im sooo  excited see yall 

### Recording Links

- https://lookout.hackclub.com/api/media/6ee5df61-956c-4f03-adf4-5b3cd5fa044e/video.mp4

## Entry 2
- ID: 14203
- Author: diaxx
- Created At: 2026-06-15T09:17:59Z

### Content

hi and welcome again to my journal today i attacked the FOC board and did 90% completion. this foc board will control almost everything of the gimbal it will move the 2 brushless motor and power them from my 3s lipo 12V i built it around a stm32f405rgt6 because its powerful enough with its clockspeed of around 168Mhz i used a step down module to step 11v to 5v then i got an ldo to get 3.3v from that 5v 


### Recording Links

- https://lookout.hackclub.com/api/media/261ad7bf-df15-4741-a416-8691a65aea68/video.mp4

## Entry 3
- ID: 14206
- Author: diaxx
- Created At: 2026-06-15T09:34:38Z

### Content

i just finished the schematics of the FOC board i added connectors to facilitate connection between sensor and motors i will hop on the pcb layout for the next journal 


### Recording Links

- https://lookout.hackclub.com/api/media/e740d2a4-c575-43ca-b38f-cbfea2605d6d/video.mp4

## Entry 4
- ID: 14592
- Author: diaxx
- Created At: 2026-06-16T18:17:43Z

### Content

FINALLY AFTER GREAT SUFFERING  i finished the FOC board layout and routing i implemented usb-c to flash and talk with the foc and also added jst pin for two encoder and one imu that is going to be inside the ball ( the spinning ball with camera lets call it the payload ball ) i thickened the vbat and motor phase trace to support their voltage  
Capture d'écran 2026-06-15 122545.png here i had to change the usb -c for the differential 
Capture d'écran 2026-06-15 132907.png
Capture d'écran 2026-06-15 144745.png also i went thru stm to assign pins to their respective role here is an image resuming that 
Capture d'écran 2026-06-15 095450.png here is the encoder that is going to be used
Capture d'écran 2026-06-14 232111.png

### Recording Links

- https://lookout.hackclub.com/api/media/5754e1eb-07df-446a-a06e-c7e1d952c2b2/video.mp4

## Entry 5
- ID: 15087
- Author: diaxx
- Created At: 2026-06-18T22:24:40Z

### Content

i made some huge changes in the cad such as i split the ball to 3d print it and added screw hole because we are professional we don't do glue here! other than that i added mounts for the cameras ,the raspberry pi zero 2w and i also modeled a slip ring cuz i didn't find in grabcad then i implemented it while adding its mount  
Capture d'écran 2026-06-14 041628.png i also added hole to mount the whole ball to the motor 

### Recording Links

- https://lookout.hackclub.com/api/media/6ea9e612-d17a-4604-8edc-575acab59e57/video.mp4

## Entry 6
- ID: 15094
- Author: diaxx
- Created At: 2026-06-18T23:37:51Z

### Content

i just set up my github repo did a good readme for this eots project i also decided to call this project: EOTS i added a bom.csv 


### Recording Links

- https://lookout.hackclub.com/api/media/4ee8fb73-376d-4626-85e3-62814cef8b55/video.mp4

## Entry 7
- ID: 15096
- Author: diaxx
- Created At: 2026-06-18T23:46:42Z

### Content

the last steps before sending this project i updated some of the cad models thanks to a person suggestion, also i made the zine 

i know its not that good but its all i could do im not proficient with Figma. I set up my github repo with a good readme added all the necessary files like bom.csv / gerber / cad model and structured them nicely with folder  
Capture d'écran 2026-06-18 184651.png

### Recording Links

- https://lookout.hackclub.com/api/media/410a64bc-7fc6-4ba3-8244-18ac1eea6165/video.mp4

## Entry 8
- ID: 15402
- Author: diaxx
- Created At: 2026-06-20T00:52:01Z

### Content

i HAD to reduce my pcba price since my BOM wasn't really optimized also i added screw hole to the pcb the total price of the pcb went from 

to this 
Capture d'écran 2026-06-20 005239.png 
### how did i do it 

i just changed passive component from extend to basic because extended component charge 3$ loading fee 

i choose the cheapest shipping 
Capture d'écran 2026-06-20 005801.png
i also picked the biggest coupons 
Capture d'écran 2026-06-20 005755.png
and here is the total 

### Recording Links

- https://lookout.hackclub.com/api/media/ff1a3a90-957c-4574-b43e-1b231e1720c8/video.mp4

## Entry 9
- ID: 15769
- Author: diaxx
- Created At: 2026-06-20T20:31:33Z

### Content

# The Last Checks 
i just optimized my bom like crazy ( made it less expensive ) switched to cheaper alternative just like what i did with pcb Assembly for exemple i switched a 7$ connector with a 3$ one same same but diff price! Additionally i made the geometry of the 3d printed metal bracked easier to print and that made the price 10$ cheaper here is how the bom was before :  
## the old bom
Capture d'écran 2026-06-18 181653.png
### THE TOTAL WAS : 3,770.84 DH ( 400$) 
## the new bom
Capture d'écran 2026-06-20 205505.png
### the total is now : 3,153.12dh ( 341.8) 

this is 617.72 dh difference 

## Now doing the last checks 
▢ The PCB is finished 
▢ 3D cad model is done 
▢ github repo is fully built and done 
▢ the bom was done and optimized 
▢ Zine page is awesomely done
▢  Firmware is ok 
▢ no floating object in the cad 

I think this is the end of our little project ( or not depends if i get reject hopefully not ! ) i am ready to click send !!!! (●'◡'●) this was fun. 

### Recording Links

- https://lookout.hackclub.com/api/media/f54878fe-931f-4c71-a32d-f38f5f914b6a/video.mp4

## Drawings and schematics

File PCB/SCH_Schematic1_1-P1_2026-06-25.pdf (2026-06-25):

# gate driver

# MCU

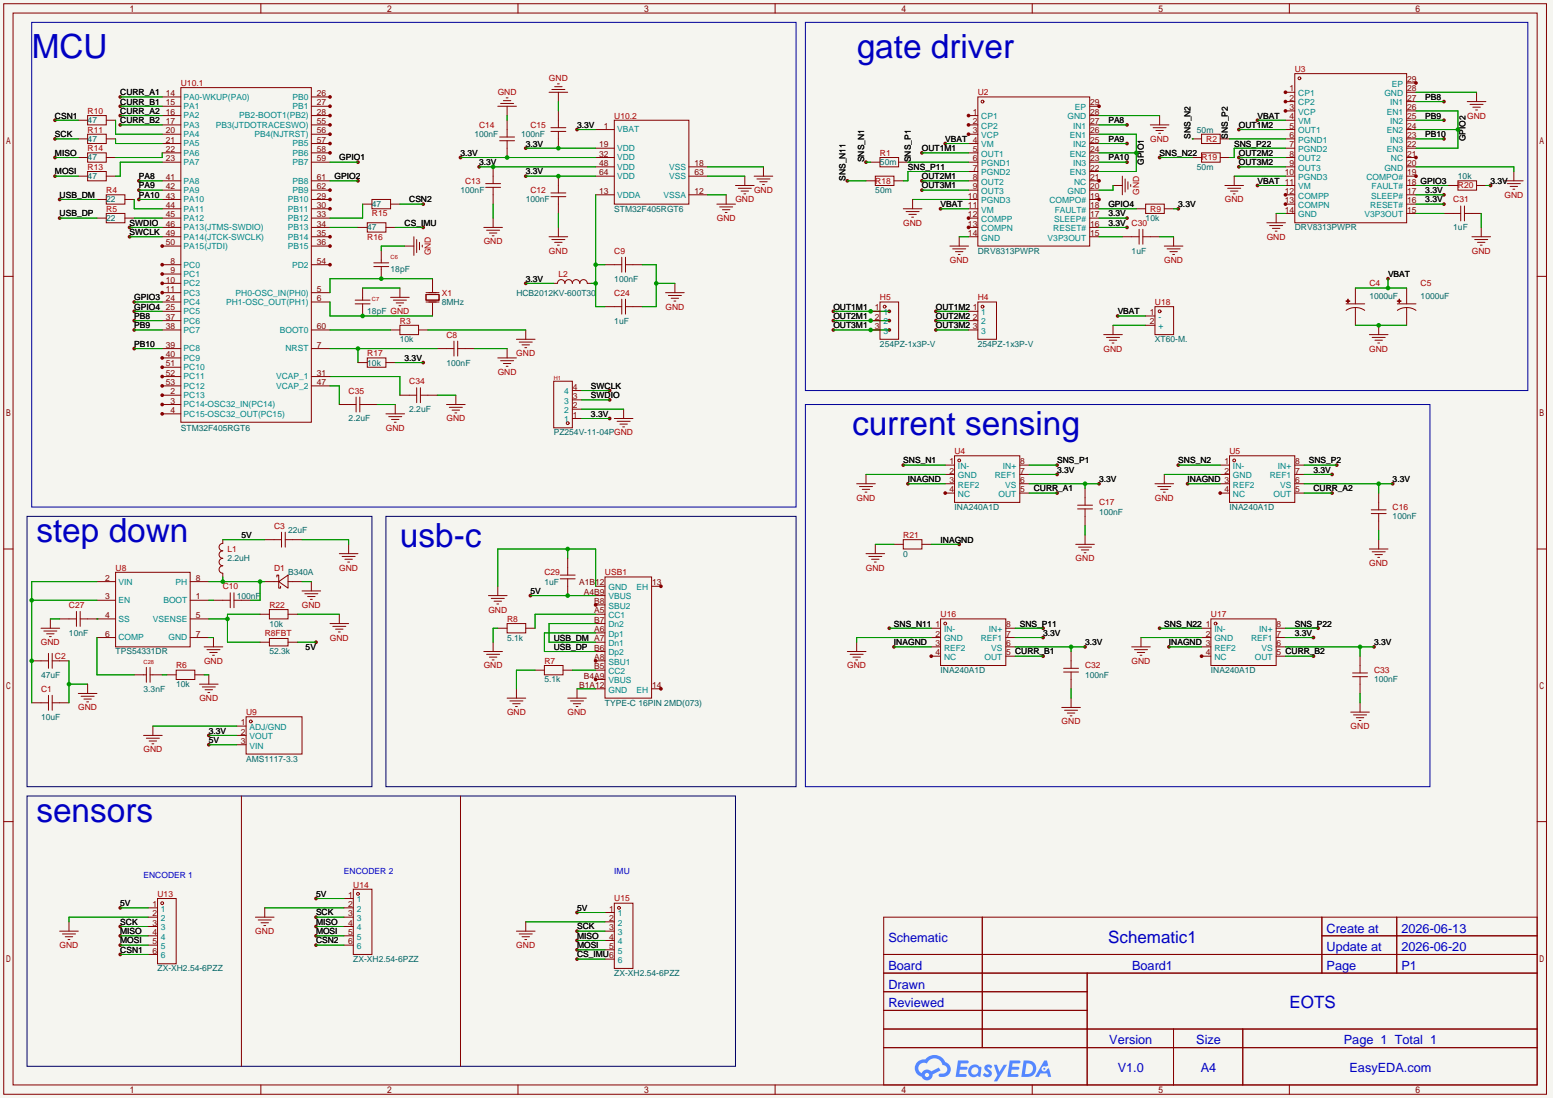
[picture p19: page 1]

Schematic | Schematic1 | Create at | 2026-06-13

Update at | 2026-06-20

Board | Board1 | Page | P1
Drawn | | EOTS
Reviewed

Version | Size | Page 1 Total 1
V1.0 | A4 | EasyEDA.com

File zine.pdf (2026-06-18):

# PROJECT EOTS PROJECT EOTS

## brushless

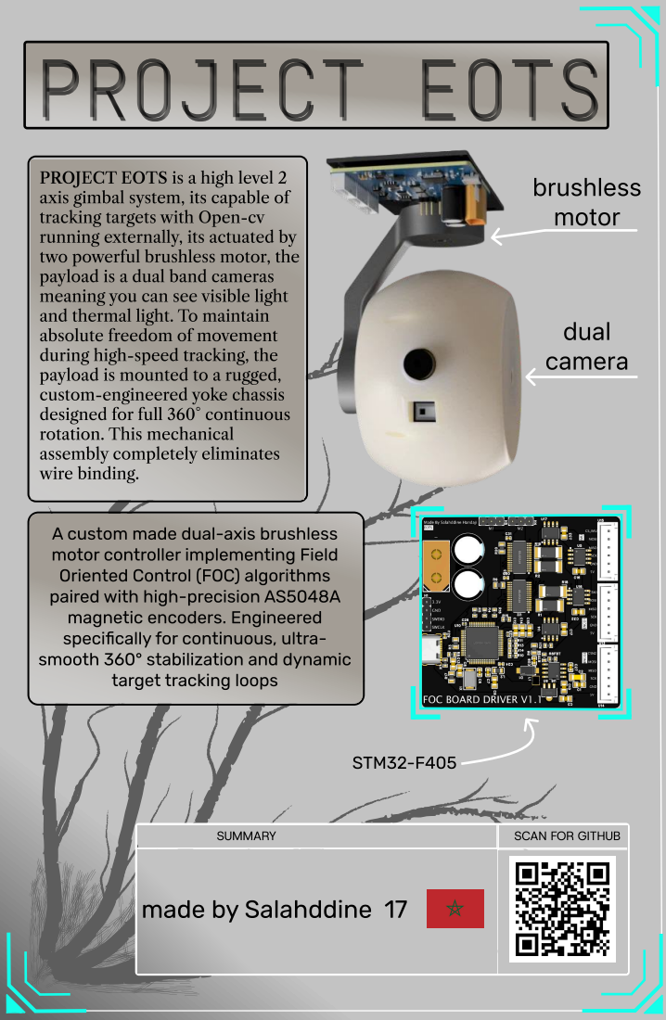
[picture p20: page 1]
motor; dual; camera; STM32-F405; SUMMARY

PROJECT EOTS is a high level 2
axis gimbal system, its capable of
tracking targets with Open-cv
running externally, its actuated by
two powerful brushless motor, the
payload is a dual band cameras
meaning you can see visible light
and thermal light. To maintain
absolute freedom of movement
during high-speed tracking, the
payload is mounted to a rugged,
custom-engineered yoke chassis
designed for full 360° continuous
rotation. This mechanical
assembly completely eliminates
wire binding.

A custom made dual-axis brushless
motor controller implementing Field
Oriented Control (FOC) algorithms
paired with high-precision AS5048A
magnetic encoders. Engineered
specifically for continuous, ultra-
smooth 360° stabilization and dynamic

target tracking loops

SCAN FOR GITHUB

made by Salahddine 17

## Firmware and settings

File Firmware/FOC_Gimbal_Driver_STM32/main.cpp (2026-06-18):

#include <SimpleFOC.h>

#define PAN_CS_PIN  PA4
#define TILT_CS_PIN PA3

SPIClass SPI_1(PB5, PB4, PB3);

MagneticSensorSPI sensorPan  = MagneticSensorSPI(PAN_CS_PIN, 14, 0x3FFF);
MagneticSensorSPI sensorTilt = MagneticSensorSPI(TILT_CS_PIN, 14, 0x3FFF);

BLDCMotor motorPan  = BLDCMotor(7); 
BLDCMotor motorTilt = BLDCMotor(7);

BLDCDriver3PWM driverPan  = BLDCDriver3PWM(PA8, PA9, PA10, PC13);
BLDCDriver3PWM driverTilt = BLDCDriver3PWM(PB6, PB7, PB8,  PC14);

float targetAnglePan  = 0.0f;
float targetAngleTilt = 0.0f;

void serialCommunicationCheck();

void setup() {
    Serial.begin(115200);
    SimpleFOCDebug::enable(&Serial);

    SPI_1.begin();

    sensorPan.init(&SPI_1);
    sensorTilt.init(&SPI_1);
    
    motorPan.linkSensor(&sensorPan);
    motorTilt.linkSensor(&sensorTilt);

    driverPan.voltage_power_supply  = 12.0f;
    driverTilt.voltage_power_supply = 12.0f;
    driverPan.init();
    driverTilt.init();

    motorPan.linkDriver(&driverPan);
    motorTilt.linkDriver(&driverTilt);

    motorPan.foc_modulation  = FOCModulationType::SpaceVectorPWM;
    motorTilt.foc_modulation = FOCModulationType::SpaceVectorPWM;

    motorPan.controller  = MotionControlType::angle;
    motorTilt.controller = MotionControlType::angle;

    motorPan.PID_velocity.P = 0.15f;
    motorPan.PID_velocity.I = 15.0f;
    motorPan.P_angle.P      = 25.0f;
    motorPan.voltage_limit  = 6.0f;
    motorPan.velocity_limit = 35.0f;

    motorTilt.PID_velocity.P = 0.12f;
    motorTilt.PID_velocity.I = 12.0f;
    motorTilt.P_angle.P      = 20.0f;
    motorTilt.voltage_limit  = 5.0f;
    motorTilt.velocity_limit = 30.0f;

    motorPan.init();
    motorPan.initFOC();

    motorTilt.init();
    motorTilt.initFOC();

    _delay(500);
}

void loop() {
    motorPan.loopFOC();
    motorTilt.loopFOC();

    motorPan.move(targetAnglePan);
    motorTilt.move(targetAngleTilt);

    serialCommunicationCheck();
}

void serialCommunicationCheck() {
    if (Serial.available() > 0) {
        String inputBuffer = Serial.readStringUntil('\n');
        inputBuffer.trim();

        if (inputBuffer.startsWith("P:") && inputBuffer.contains(",T:")) {
            int splitIndex = inputBuffer.indexOf(",T:");
            
            String panSubstring  = inputBuffer.substring(2, splitIndex);
            String tiltSubstring = inputBuffer.substring(splitIndex + 3);

            targetAnglePan  = panSubstring.toFloat();
            targetAngleTilt = tiltSubstring.toFloat();
        }
    }
}

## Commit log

2026-06-18 Fix image reference in README for schematics
2026-06-18 Rename EOTS BOM.csv to BOM.csv
    [BOM.csv]
2026-06-20 Revise BOM with updated prices and quantities
    Updated component prices and quantities in the Bill of Materials. Adjusted total cost and budget summary due to optimizations.
2026-06-21 Cleaned up layout and added project files
    [BOM.csv, PickAndPlace.csv]
2026-06-22 Replace CAD render images in README
    Updated images in README with new CAD renders.
2026-06-22 Fix formatting for metal chassis description in README
2026-06-22 Revise BOM with updated quantities and prices
    Updated quantities and prices for several components in BOM.
    [BOM.csv]
2026-06-25 Change image path for Wire Diagram in README
    Updated image reference in the Wire Diagram section.
